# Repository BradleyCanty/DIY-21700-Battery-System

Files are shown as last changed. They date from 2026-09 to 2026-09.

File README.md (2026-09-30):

# DIY-21700-Battery-System
## Introduction
This is a do-it-yourself battery system intended for use with Unmanned Aerial Vehicles or Unmanned Ground Vehicles.

It consists of...

1) a battery using lithium ion 21700-form-factor cells, with battery configurations spanning from 6s3p to 12s6p
2) a vehicle adapter with place-to-lock/press-to-unlock latching mechanism
3) an off-vehicle charging station

(12s4p battery system configuration shown below)

<p align="center">
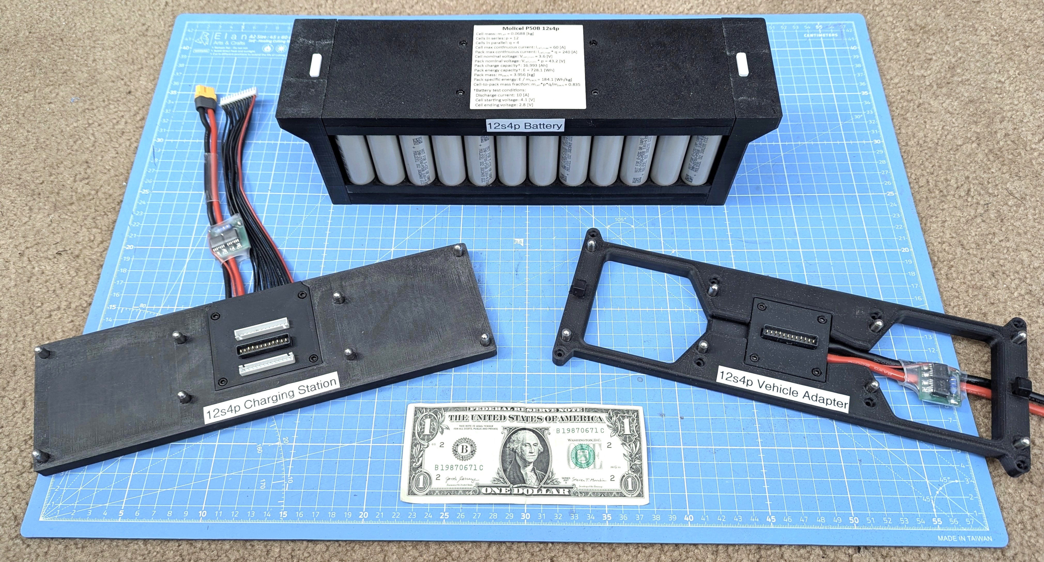
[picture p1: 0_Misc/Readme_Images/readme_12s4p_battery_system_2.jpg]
  
</p>

**This is a complete and working system, with all design files (CAD and PCB design) provided for your use:**\
Multiple battery system configurations have been built and flight tested. Additionally, all CAD models have been 3D printed to ensure they work as intended. Finally, if none of the configurations presented here suit your needs then you can create your own battery configuration, since all CAD files (Solidworks part files and STLs) and PCB design files (KiCad project files) are included here for your use.

**Version 2 will have cell voltage and temperature monitoring safety features (sent as a BATTERY_STATUS message over MAVLink to MAVLink-compatible autopilot software, such as ArduPilot and PX4) so star this repo for updates**

## Purpose
The parametric nature of this system allows designing and building a battery system specific to your vehicle's requirements. As such, **the value add of this system is threefold:**
1) you can use cells of your choice (i.e., can optimize for either power output or energy capacity) in a configuration suitable for your vehicle's operating envelope
2) you can enjoy a significant cost savings (~50% discount at the time of this writing) by building it yourself (see 'Bill of Materials' section for cost info)
3) the battery's latching mechanism presents a common interface for battery swapping (either manually or by robot arm); this is important since battery swapping vastly increases system uptime when compared with on-board charging

## Battery Mounting Choice
This battery system is designed such that the battery itself is top-mounted onto the vehicle its powering (and top-mounted onto its charging station). This mounting method was chosen to simplify battery swapping (either by human hand or by robot gripper); the process to swap the battery is as follows:
1. get within close proximity of the battery
2. translate grippers directly over the battery
3. rotate grippers to be aligned with the battery end plates
4. translate grippers underneath each end plate ledge
5. close grippers such that the end plate buttons are pressed down, thus unlatching the battery from the vehicle adapter
6. lift battery away from the vehicle
7. carry battery to its charging station

A similar but reversed process occurs for taking a fully charged battery off its charging station to the vehicle.

If you intend for such a battery to power your multirotor you might ask: "wouldn't the multirotor be top heavy, thereby adversely affecting stability and control?". The simple answer is no, it wouldn't **if you mount the battery directly above the bulkhead where the motor arms are mounted to the body**. In doing this, the center of gravity moves closer to the thrust plane (i.e. the plane where the rotors spin), which decreases overall inertia and thereby increases control responsiveness. So the overall impact is positive, not adverse. As final proof of functionality, I have personally flight tested a multirotor using a 12s4p battery, with no stability or control issues whatsoever.

(12s4p battery and vehicle adapter used on large quadcopter shown below)

<p align="center">
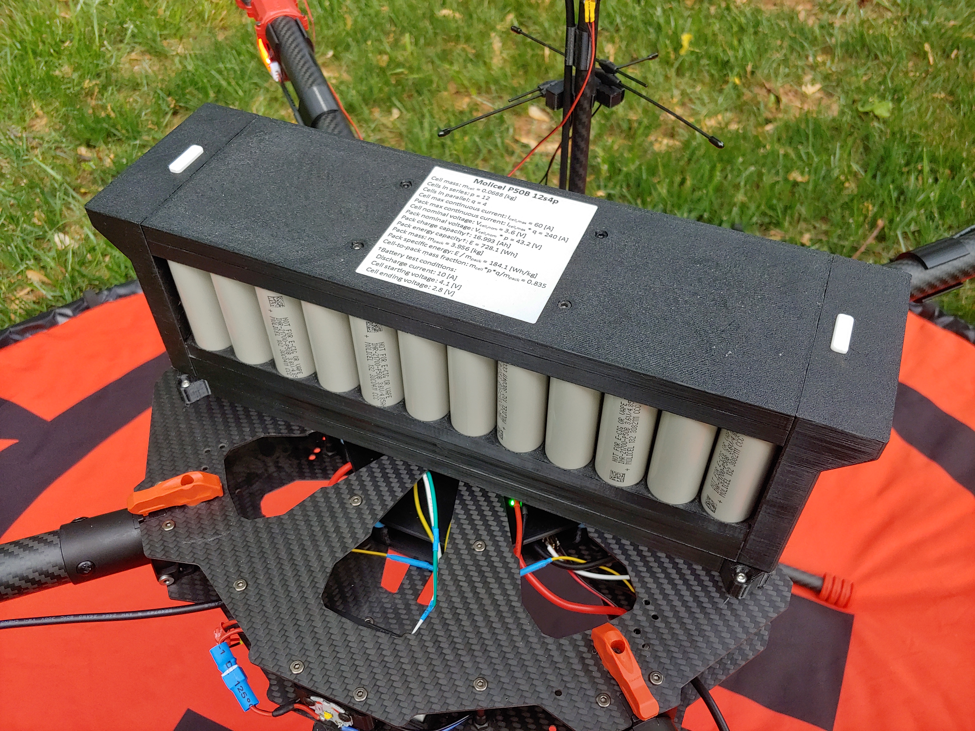
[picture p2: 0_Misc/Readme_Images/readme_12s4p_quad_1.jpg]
  
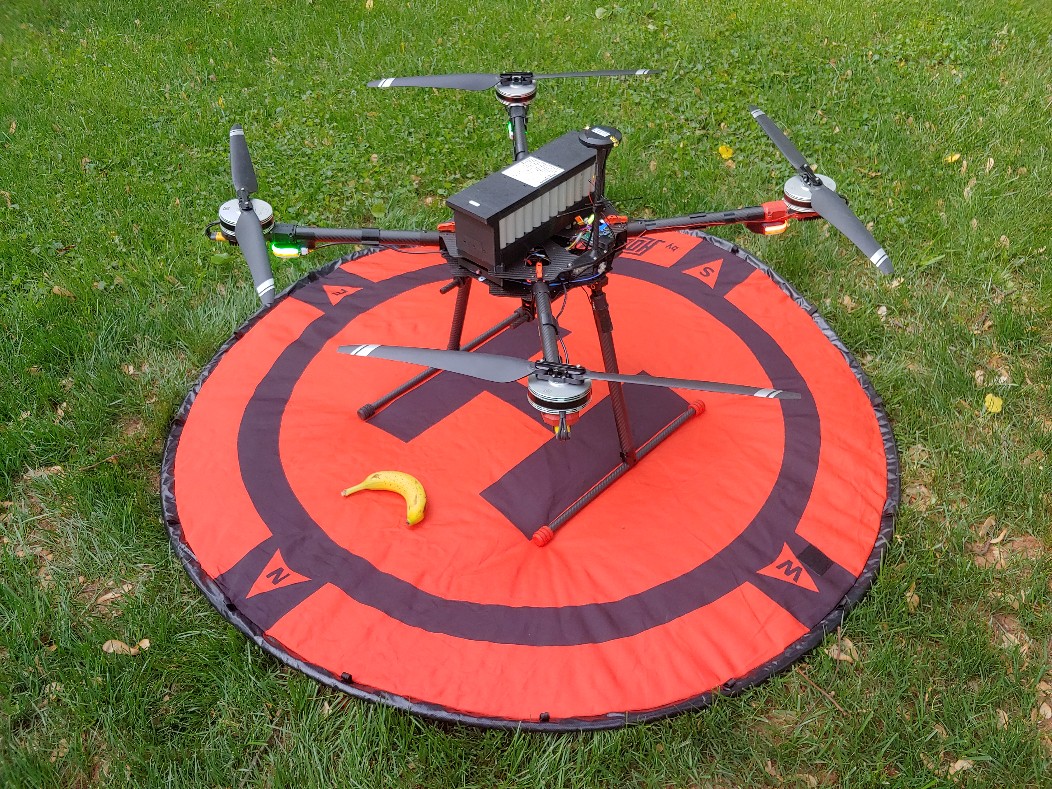
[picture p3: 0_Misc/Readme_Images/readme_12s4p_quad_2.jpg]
  
</p>

Details on mounting the vehicle adapter to the vehicle can be found in Build Step 7: [Integrate vehicle adapter into vehicle](5_Integration_and_Test_Instructions/1_Vehicle_Adapter_Integration_Instructions/vehicle_adapter_integration_instructions.md)

## Cell Form Factor Choice
Considering the cell form factor, **21700 cells** (i.e. cylindrical cells having 21[mm] height and 70[mm] length) **are used in the battery since they are cheap, easily obtained, and have high gravimetric energy density**. In comparison to other cells types, 18650 cells tend to have lower gravimetric energy density, while 4680 cells, prismatic cells, and pouch cells aren't widely available to the general public (as of late 2026). Concerning battery design, the battery configuration is defined by its number of cells in series (which sets its voltage) and its number of cells in parallel (which sets its charge capacity and its max current draw limit). In the system presented here, the possible number of cells in series ranges from 6 to 12, while the possible number of cells in parallel ranges from 3 to 6. That is, the smallest possible battery configuration is one having 6 cells in series and 3 cells in parallel (18 cells total), while the largest battery configuration is one having 12 cells in series and 6 cells in parallel (72 cells total).

(6s3p and 12s6p battery system configurations shown below)

<p align="center">
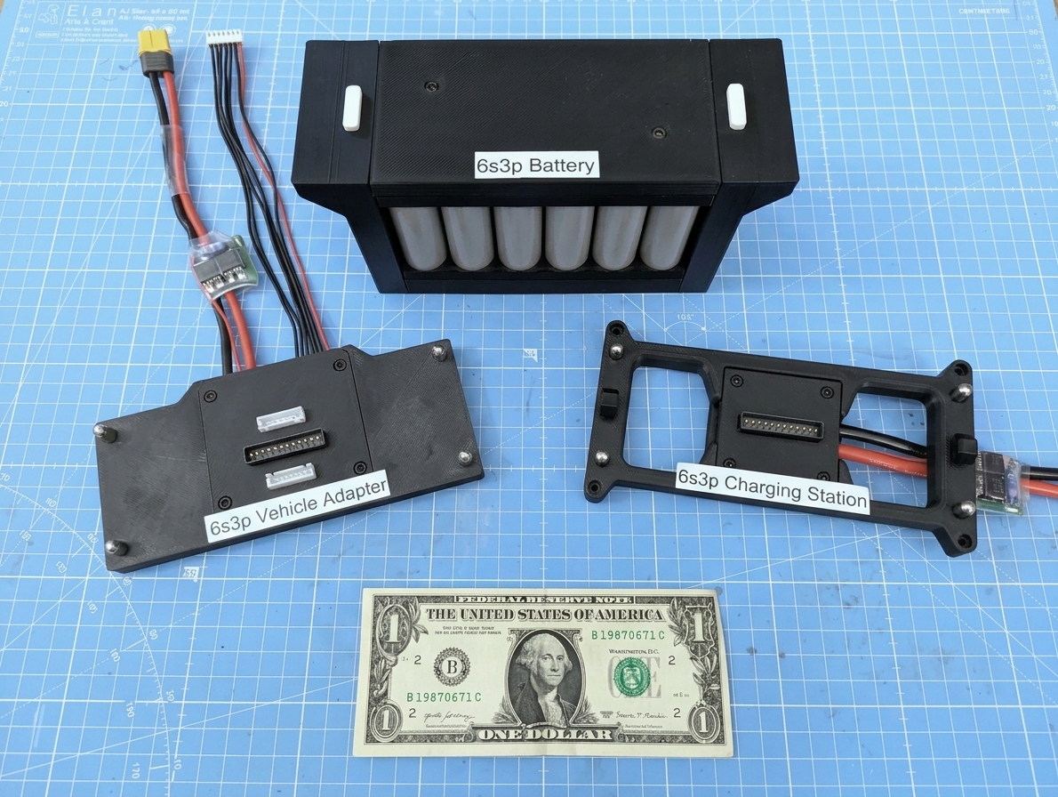
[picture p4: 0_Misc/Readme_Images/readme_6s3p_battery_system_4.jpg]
  
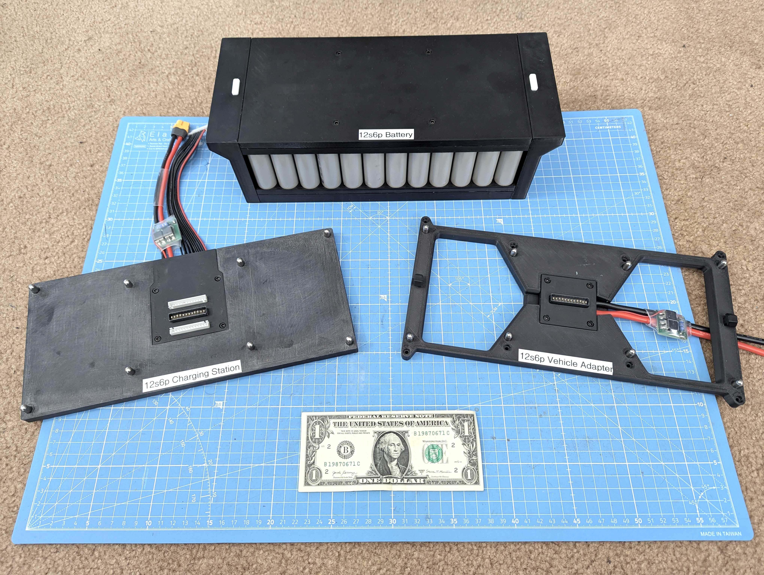
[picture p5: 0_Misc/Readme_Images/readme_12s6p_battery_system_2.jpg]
  
</p>

As a final note, **the cell-to-pack mass fraction across all battery configurations is found to be around 83%**. This value is important since once you select a specific 21700 cell to use, you can then estimate the battery's total mass and the battery's gravimetric energy density:\
$m_{battery} \approx m_{cell} * M * N / CPMF$ = battery mass [kg]\
where\
$m_{cell}$ = cell mass [kg]\
$M$ = number of cells in series\
$N$ = number of cells in parallel\
$CPMF$ = cell-to-pack mass fraction

$E_{battery}^* = (battery\ nominal\ voltage) * (battery\ charge\ capacity)$\
&nbsp; &nbsp; &nbsp; &nbsp; &nbsp; &nbsp; &thinsp;= $(M * V_{cell, nominal})*(N * Q_{cell,expected}) / m_{battery}$\
&nbsp; &nbsp; &nbsp; &nbsp; &nbsp; &nbsp; &thinsp;= gravimetric energy density [Wh/kg]\
where\
$V_{cell, nominal}$ = nominal cell voltage = 3.6[V] (for li-ion cell)\
$Q_{cell,expected}$ = expected cell charge capacity for normal vehicle operation (computed using the process outlined in 'Steps for Selecting a Battery Configuration' section found below)

For example, for a battery having 8 cells in series and 5 cells in parallel (i.e. MsNp = 8s5p) using EVE 50PL 21700 cells, we have\
$m_{cell} = 0.066 [kg]$ (real-world value... datasheet gives 0.072 [kg] per cell)\
$M$ = 8\
$N$ = 5\
$CPMF$ = 0.83\
$Q_{cell,expected}$ = 4.5 [Ah]

Then, battery mass and gravimetric energy density are computed to be\
$m_{battery} \approx 0.066 * 8 * 5 / 0.083 =  3.18$ [kg]\
$E_{battery}^* = (8 * 3.6)*(5 * 4.5) / 3.18$ = 203.8 [Wh/kg]

## Safety
Additionally, safety is paramount. A temperature sensor circuit consisting of a microcontroller and busbar voltage sensing is in progress (I had assumed thermistors would work in the cell failure detection role, but apparently the thermal mass of the busbar is too large to detect it in time). I am in the process of designing and prototyping a circuit which detects voltages at each busbar and sends them in MAVLink packets over UART to the flight controller (running either Ardupilot or PX4), with options of alerting the pilot or autolanding the vehicle if a measured busbar voltage is lower than some threshold. **The software development, physical packaging, and testing have posed significant issues which require a non-trivial amount of iteration, time, and money: I am working through these issues, but at some point I need to call a "pencils down" and declare victory, so Version 1 is without this safety feature. However, I assure you that Version 2 will have this safety feature, so stay tuned for that.** Additionally, I am in the process of making a low voltage alarm circuit featuring a buzzer and orange LED lights which buzz and flash upon low voltage detection, which I intend to include in Version 2 of this project.

Concerning the electrical system limitations, the PCBs (the 'Battery Board', 'Vehicle Adapter', and 'Antispark Board') are designed to handle 60 amps of continuous current (assuming a maximum temperature rise of 20°C). **You should consider the 60 amps of continuous current limitation as the primary limiting factor in your selected configuration.** This current limitation is written out on each PCB via silkscreen text. Note that this is max continuous current, <ins>not max short-duration current</ins>: max short-duration current is dictated by the 21700 cell you choose (should be listed in its datasheet) and the number of cells used in parallel. Specifically, its given by:

$I_{max\ total,short\ duration}$ = $I_{max\ cell} * N$\
where\
$N$ = number of cells in parallel

## DIY or Build from a Kit
Building this system consists of many steps (see 'Build Steps' section), and requires specific tools (see 'Required Tools' section). As a consequence, many people may find that doing this on their own is too advanced for them. Therefore, a kit is available to make the the build process easier: in essence, all you need to do upon receiving the kit is
1) Insert your favorite cells (purchased separately) into the fully-prepared 3D printed frames
2) spot weld the busbars to the cell terminals
3) Solder the balance cable wires to the busbars
4) Cut and solder the 8 AWG power wires to the battery PCB
5) fasten the fully-prepared 3D printed parts and pre-populated PCBs together with screws
6) Test the battery by performing a few charge/discharge cycles on your battery charger (the battery charger is not included in the kit)

Then, the tools required for building the battery system from the kit is
1) a suitable spot welder
2) soldering iron
3) metric hex wrenches
4) a suitable battery charger

Kit contents, pricing, and ordering information can be found [here](0_Misc/build_kit_info.md).

Whether you are building from raw materials or building from the kit, the 'Build Steps' section found below contains pictures and descriptions at each step to aid in the build process.

## Battery System Components in Detail
The battery system consists of the following components:
1) the battery
2) the vehicle adapter
3) the charging station

Each is explained in turn

### The Battery
Each component is sized according to the chosen battery configuration. Possible battery configurations range from 6 to 12 cells in series, and 3 to 6 cells in parallel. Spelled out, these configurations are:
* Six in series:
    - Three in parallel (6s3p)
    - Four in parallel (6s4p)
    - Five in parallel (6s5p)
    - Six in parallel (6s6p)
* Eight in series:
    - Three in parallel (8s3p)
    - Four in parallel (8s4p)
    - Five in parallel (8s5p)
    - Six in parallel (8s6p)
* Ten in series:
    - Three in parallel (10s3p)
    - Four in parallel (10s4p)
    - Five in parallel (10s5p)
    - Six in parallel (10s6p)
* Twelve in series:
    - Three in parallel (12s3p)
    - Four in parallel (12s4p)
    - Five in parallel (12s5p)
    - Six in parallel (12s6p)
  
  The battery consists of
  - two frames, which hold the cells between them
    <p align="center">
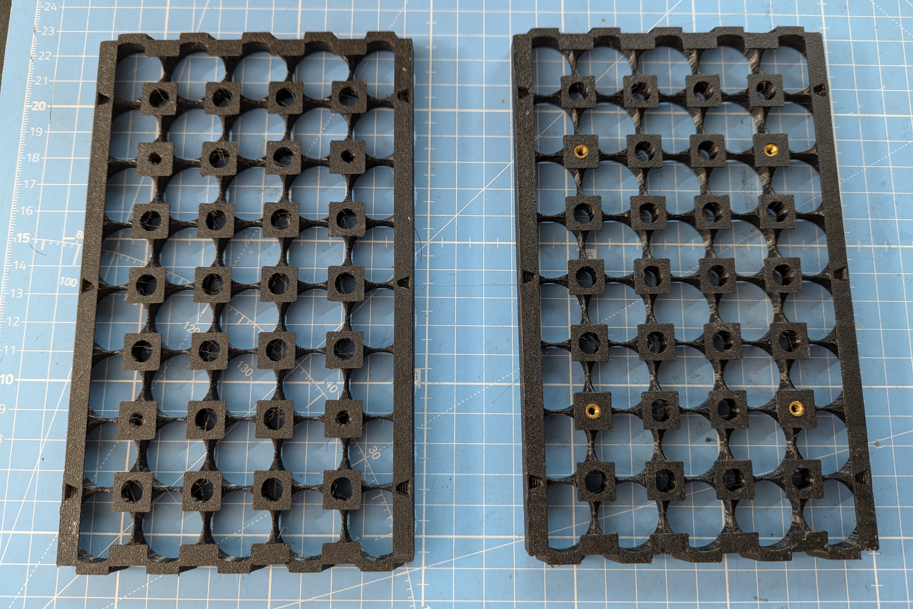
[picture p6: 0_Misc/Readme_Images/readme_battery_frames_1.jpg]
      
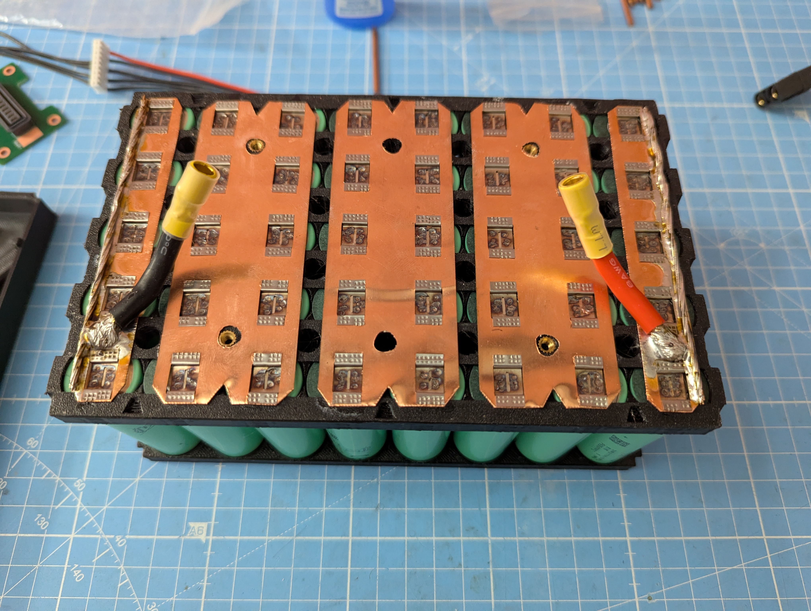
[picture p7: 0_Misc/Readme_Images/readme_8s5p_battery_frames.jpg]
      
    </p>
    
  - a top plate, which covers the top frame
    <p align="center">
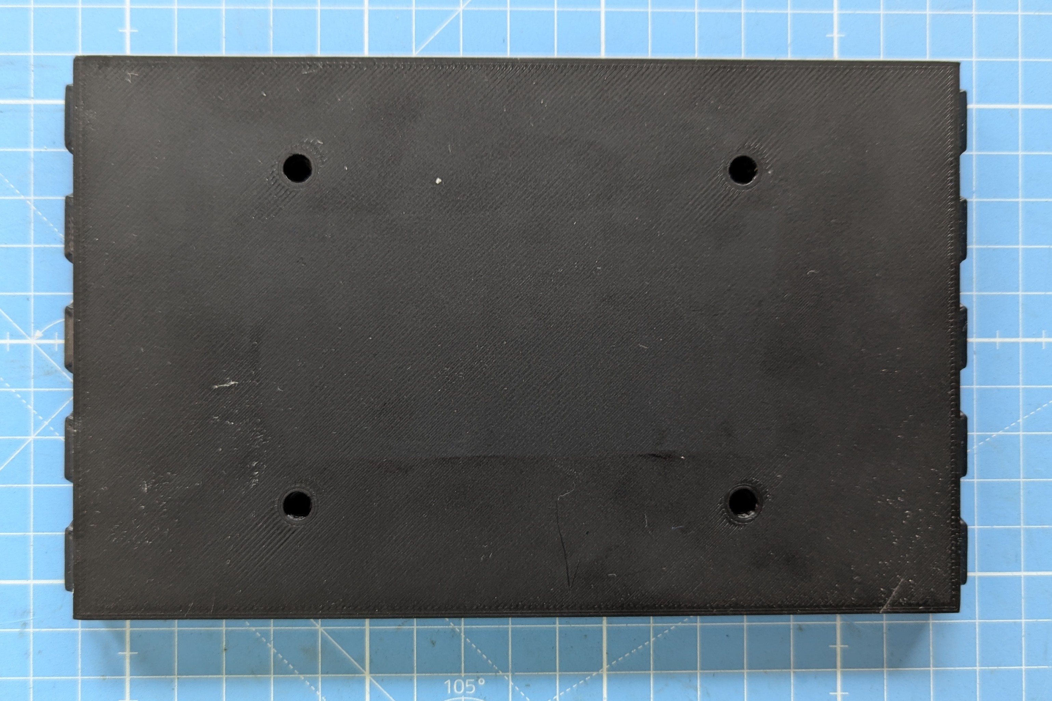
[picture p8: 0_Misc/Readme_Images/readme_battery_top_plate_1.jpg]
      
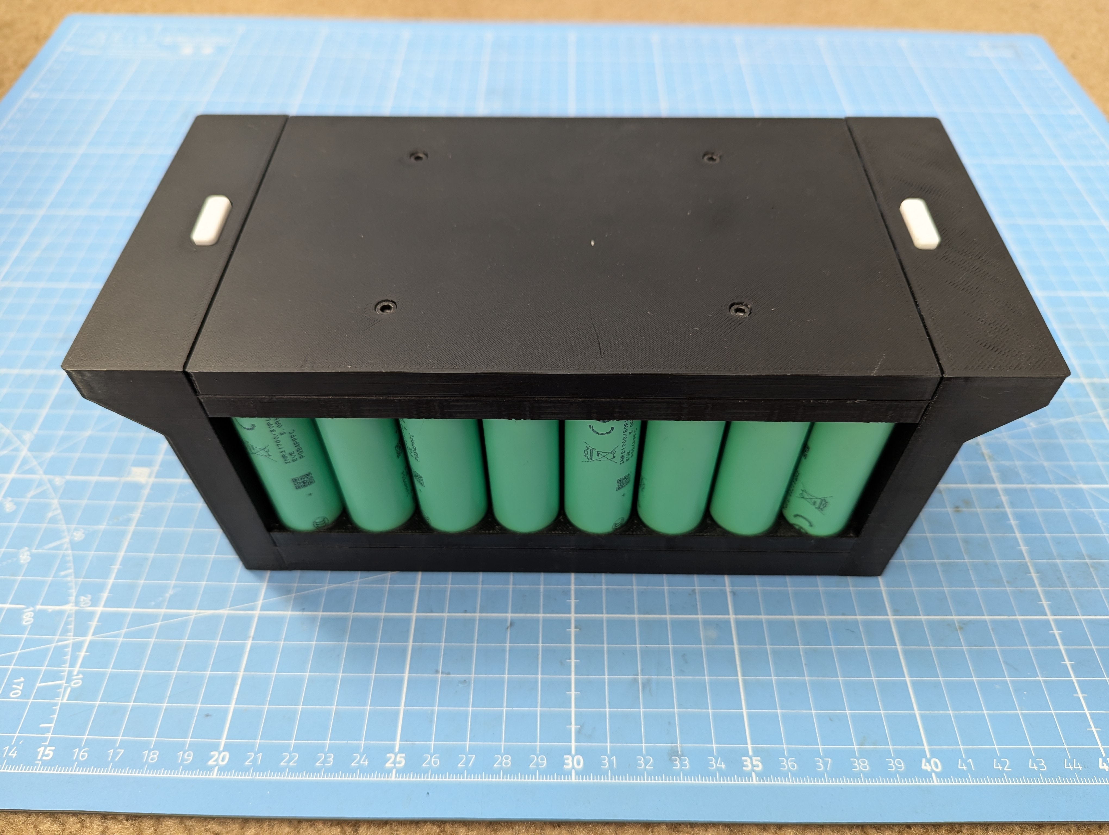
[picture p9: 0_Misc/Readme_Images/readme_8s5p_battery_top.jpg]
      
    </p>

  - a bottom plate, which connects with the bottom frame and houses the female 12-pin power and balance connectors
    <p align="center">
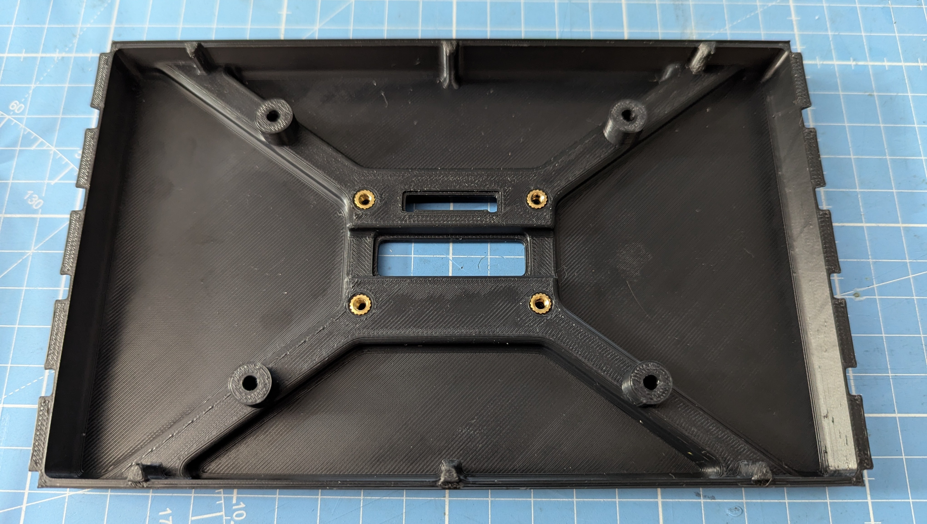
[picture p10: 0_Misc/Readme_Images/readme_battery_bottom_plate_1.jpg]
      
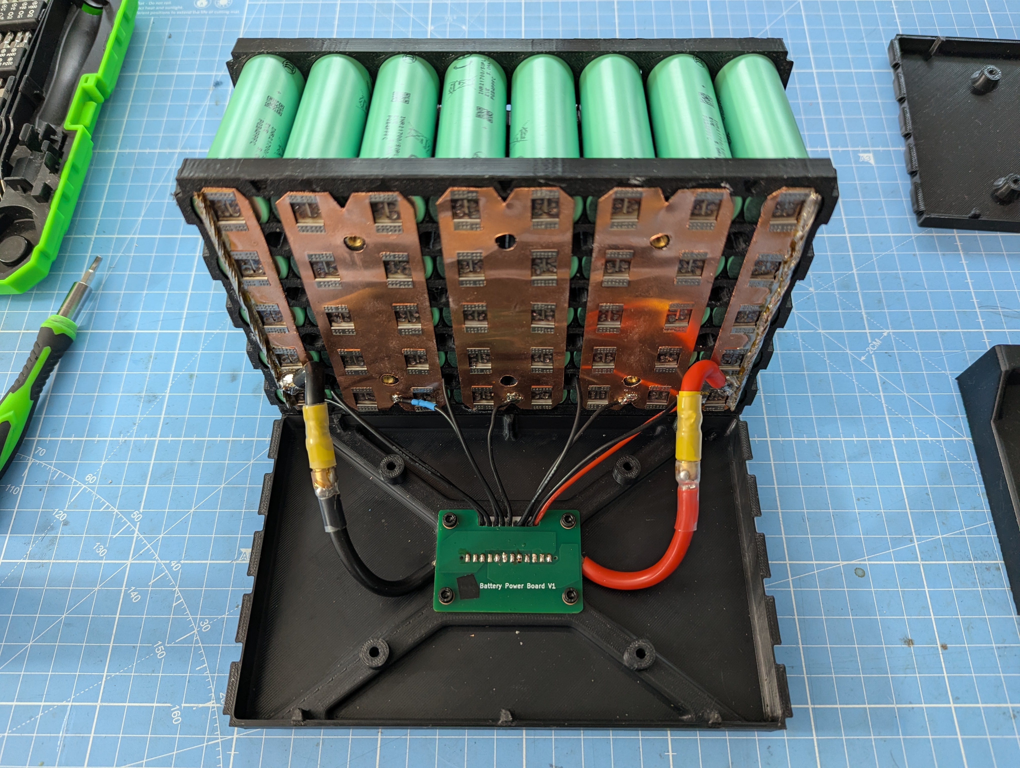
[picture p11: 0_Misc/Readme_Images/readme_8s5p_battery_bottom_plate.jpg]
      
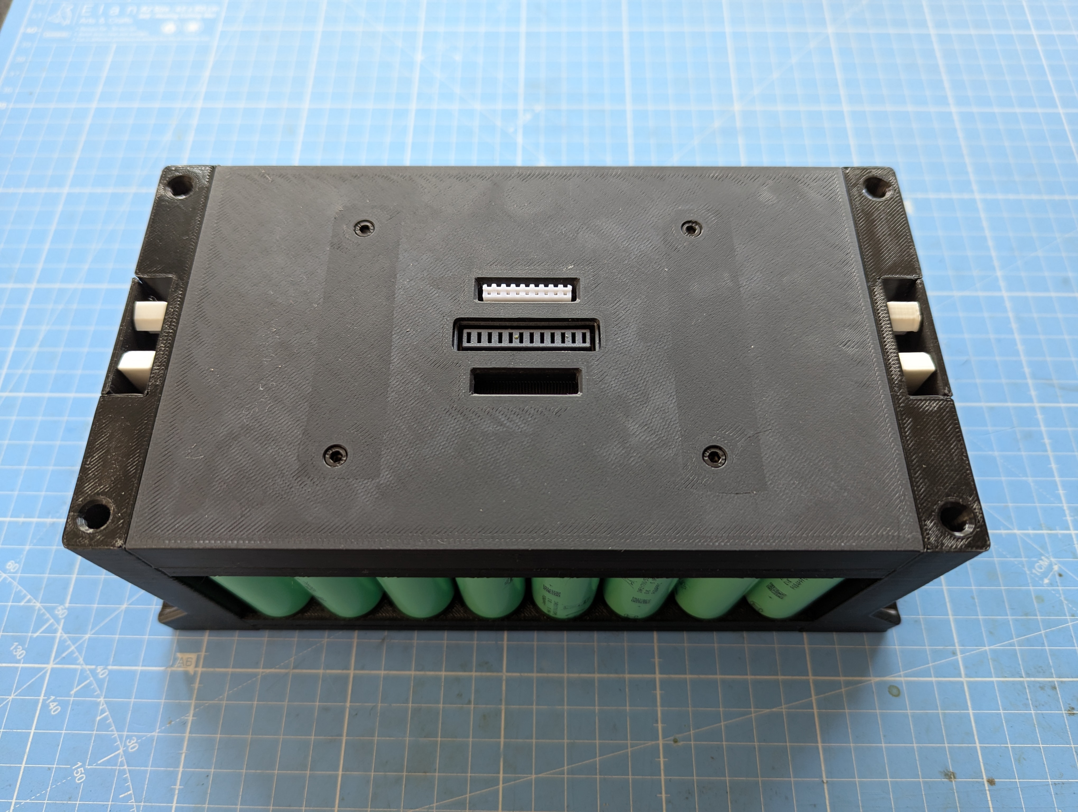
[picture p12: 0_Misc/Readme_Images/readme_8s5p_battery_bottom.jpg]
      
    </p>
    
  - two end plates, which clamp the frames together and serve as handles containing the button-press-to-unlatch mechanism
    <p align="center">
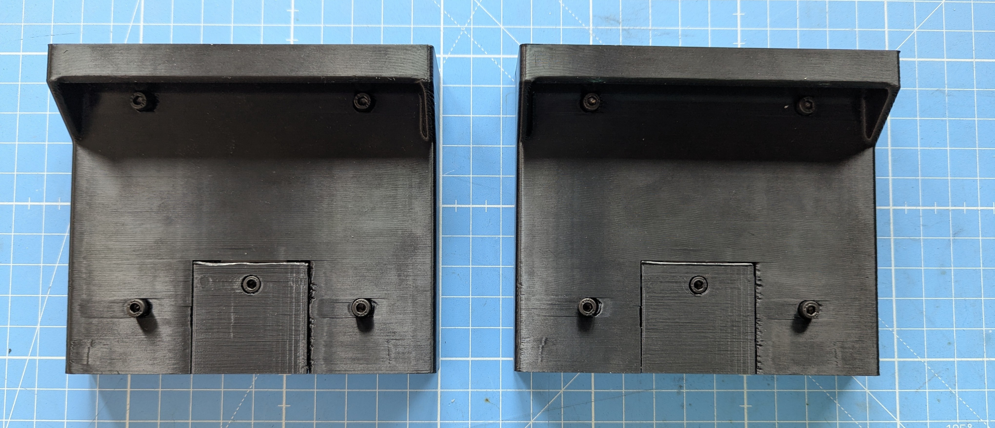
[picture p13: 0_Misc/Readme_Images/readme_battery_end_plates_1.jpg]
      
    </p>
  
### The Vehicle Adapter
Connects the battery with the vehicle, both mechanically and electrically. For the mechanical interface, it has two latches which interface with the two button-press-to-unlatch mechanisms on either end of the battery. For the electrical interface, it has a male 12-pin connector.
  <p align="center">
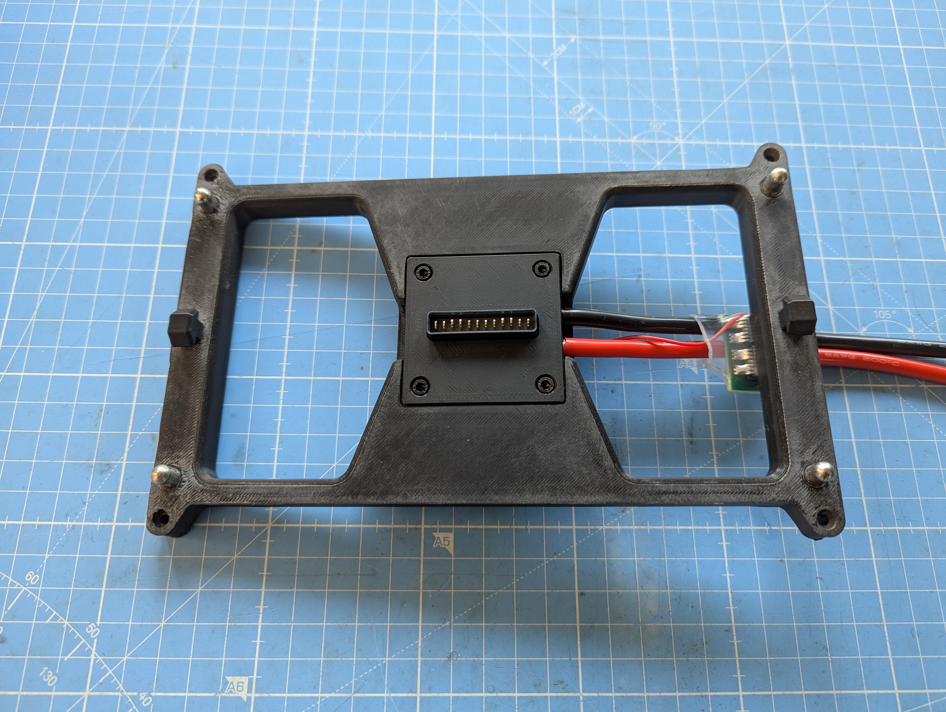
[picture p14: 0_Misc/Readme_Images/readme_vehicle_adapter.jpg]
    
  </p>

### The Charging Station
Interfaces the battery with a standard RC battery charger via XT60 connector for power and JST-XH connector for balancing. Again, <ins>this is not a charger itself: its an interface between the battery and the charger</ins>.
<p align="center">
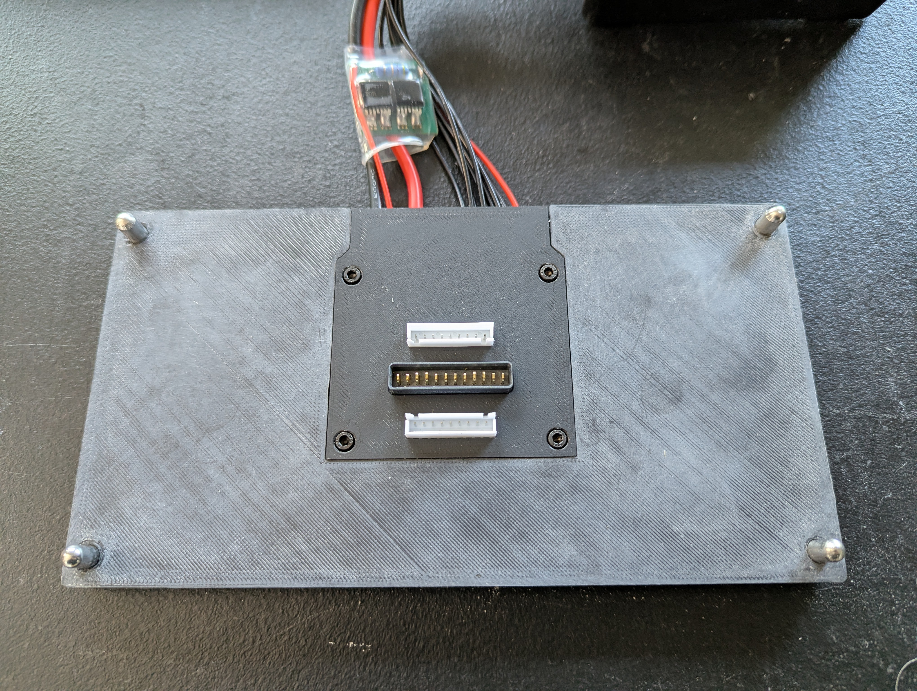
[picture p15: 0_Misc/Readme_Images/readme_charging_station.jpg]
  
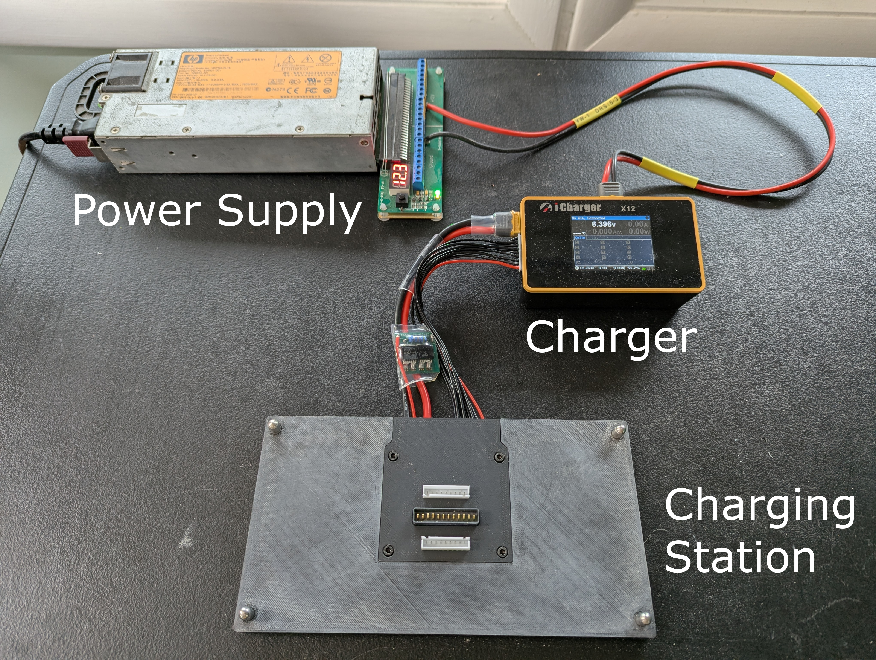
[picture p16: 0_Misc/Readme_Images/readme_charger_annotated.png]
  
</p>

## Steps for Selecting a Battery Configuration
In general,\
**The number of cells in series determines the battery voltage:**\
$battery\ max\ voltage = (cell\ max\ voltage) * (number\ of\ cells\ in\ series)$\
where\
$cell\ max\ voltage$ = 4.1 V (for LiIon cells)

**The number of cells in parallel determines the battery charge capacity:**\
$$battery\ charge\ capacity = (cell\ expected\ charge\ capacity) * (number\ of\ cells\ in\ parallel)$$\
where\
$cell\ expected\ charge\ capacity$ = a function of expected average current draw in cruise (fixed wing) or hover (VTOL)

Specifically, to find the battery's expected charge capacity, check the 21700 cell's datasheet for the plot of Voltage vs Charge Capacity (which contains curves of various discharge rates) and then match your vehicle's expected average current draw divided by the number of cells in parallel to the corresponding discharge rate curve in the plot. Finally, find the cell's capacity corresponding to an "empty" voltage of around 2.8 V, and then multiply it by the number of cells in parallel to get the battery's charge capacity.

For example, suppose you are using Molicel P50B cells in an 8s5p battery configuration on a vehicle expected to draw 1300 Watts of power in nominal operation, then the steps to find the expected charge capacity are as follows: 

1) Compute the average discharge current in nominal operation:\
   $I_{avg}$ = $P_{nominal}$ / $V_{batt,nominal}$ = $P_{nominal}$ / ($V_{cell,nominal}$ * M)\
   where\
   M = number of cells in series = 8\
   $V_{cell,nominal}$ = li-ion cell nominal voltage = 3.6V
   
   Plugging in the values...\
   $I_{avg}$ = 1300 / (3.6 * 8) = 45.1 Amps
   
2) Compute the discharge rate per cell: 45.1 Amps / 5 cells in parallel = 9.03 Amps
3) Find the Voltage vs Charge capacity plot in the Molicel P50B datasheet
4) On the plot, draw a horizontal line at the cutoff voltage (here 2.8V) across the plot, and stop upon reaching the curve corresponding to the cell's discharge rate (here the 10 Amp curve)
5) On the plot, draw a vertical line to the abscissa to obtain the cell's nominal charge capacity
(see plot below)

<p align="center">
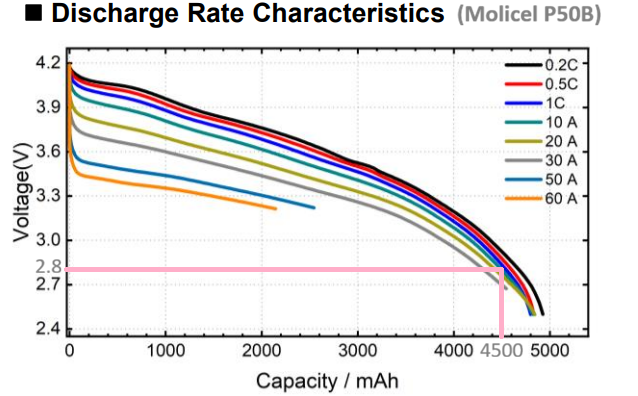
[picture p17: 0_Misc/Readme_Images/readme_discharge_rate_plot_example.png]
  
</p>

6) Finally, compute the battery's nominal charge capacity:\
   $Q_{batt,nominal}$ = $Q_{cell,nominal}$ * M\
   where\
   M = number of cells in parallel = 5

   Plugging in the values...\
   $Q_{batt,nominal}$ = 4500 * 5 = 22500 mAh = 22.5 Ah

Once battery nominal charge capacity is found, you can **compute the vehicle's expected endurance** (i.e. operating time under nominal conditions) using the following equation:\
t = $V_{batt,nominal}$ * $Q_{batt,nominal}$ / P\
where\
$V_{batt,nominal}$ = $V_{cell,nominal}$ * M

Using the values from the previous example, we have...\
t = (3.6 * 8) * 22.5 / 1300 = 0.498 hours = 29.9 minutes

This is all predicated on the accuracy of your predicted power draw, which is a function of your payload mass, battery mass, structure mass, and the type of motors (and, for multirotors, the size of the rotors) used on the vehicle. **So, in summary, selecting a battery configuration is an iterative process.**

For a multirotor, the appropriate battery configuration can be determined using this [multirotor design methodology](0_Misc/multirotor_design_methodology.md).

## Required Tools
* Soldering iron (for general soldering)
* Threaded insert soldering iron tip 
* Hot plate (for SMD soldering)
* Spot welder (for battery bus bar welding)
* 3D printer
* Deburr tool (for removing edge artifacts from 3D prints)
* Wire stripper
* Wire cutter
* Super glue
* Sheet metal shears (for cutting busbars)
* Hand drill or drill press (for cutting wire pass-through holes into busbars)

## Bill of Materials (BOM)
The battery BOM is found [here](3_Bill_of_Materials/battery_bom.md)

The vehicle adapter BOM is found [here](3_Bill_of_Materials/vehicle_adapter_bom.md)

The charging station BOM is found [here](3_Bill_of_Materials/charging_station_bom.md)

## Build Steps
### Things you should know before starting:
* ASA filament is used in all the 3D printed parts since it's ultraviolet resistant, so it can be left outdoors without degrading in strength. However, 3D printing it releases toxic fumes (specifically, printing it releases volatile organic compounds along with ultrafine particles, either of which may be carcinogenic), so use a fan-filter system when printing ASA. Also, ASA is prone to warping and so must be printed in a heated enclosure. Even with a heated enclosure, a brim is often needed on large parts to keep them from peeling away from the print bed. If the peeling at edges occurs at any time during the print, its a failed print so cancel it and reprint it with a 5 mm increase to the brim width. Do this iteratively until the print is successful.
* The printed circuit boards (PCBs) can be manufactured by uploading the zipped gerber files (provided in the repo) to a PCB manufacturer, such as PCBWay or JLCPCB
* The PCB components can be purchased from electronic component suppliers, such as DigiKey or Mouser, but know that you will need to hand-solder the through-hole components and hot plate solder the SMD components
* The build process is very frustrating and time-consuming, especially
    - 3D printing the parts, with ASA prints likely to fail due to warping
    - populating the antispark circuits with SMD components and soldering them using a hot plate
    - cutting wires to length and soldering them
    
    To save time and frustration, pre-made kits for each battery configuration are available for purchase: see 'DIY or Build from a Kit' section above for details on ordering a kit.

### To make the build process as simple as possible, proceed in this order:
  1. **Decide on a battery configuration**
  2. **Order the required PCBs and associated components:**\
     each system needs two antispark PCBs, one charging station PCB (pick the one that matches your configuration), one battery PCB (pick the one that matches your configuration), and one vehicle adapter PCB, all found [here](2_PCB_Files). See the READMEs for BOMs and ordering information.
     
  4. **Build the antispark boards:** instructions found [here](4_Build_Instructions/1_Antispark_Build_Instructions/antispark_build_instructions.md)
  5. **Build the charging station:** instructions found [here](4_Build_Instructions/2_Charging_Station_Build_Instructions/charging_station_build_instructions.md)
  7. **Build the battery:** instructions found [here](4_Build_Instructions/3_Battery_Build_Instructions/battery_build_instructions.md)
  8. **Build the vehicle adapter:** instructions found [here](4_Build_Instructions/4_Vehicle_Adapter_Build_Instructions/vehicle_adapter_build_instructions.md)
  9. **Integrate vehicle adapter into vehicle:** instructions found [here](5_Integration_and_Test_Instructions/1_Vehicle_Adapter_Integration_Instructions/vehicle_adapter_integration_instructions.md)
  10. **Perform vehicle operating envelope testing:** instructions found [here](5_Integration_and_Test_Instructions/2_Vehicle_Envelope_Testing_Instructions/vehicle_envelope_testing_instructions.md)

## TO DO
### V1 TO DO IMMEDIATELY
* Consolidate and simplify the battery sizing methodology

### V1 TO DO LATER
* Take pictures of antispark circuit build and put into instructions
* Complete the 'Perform vehicle operating envelope testing' instructions

### V2 TO DO IMMEDIATELY
* Replace JST-XH balance connectors used in battery interface with machine header pins: female on battery, male on vehicle adapter and charging station
* Implement safety features: measure voltages at each busbar, and measure temperatures at two cells, and report as a BATTERY_STATUS message over MAVLink
* Refactor end plate latching mechanism to have clamp-from-top-to-unlatch, replacing the button-press-to-unlatch. This makes the battery usable on fixed-wing platforms, since battery swapping operations interact with the top surface only, as opposed to V1 where side clasping is required. It will also probably make it easier to automate battery swapping via robot arm, due to the simplified interface.

### V2 TO DO LATER
* Replace balance wires with a BMS
* Extend battery configurations to 24s12p

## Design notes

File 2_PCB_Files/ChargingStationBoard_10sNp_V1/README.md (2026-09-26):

## KiCad 3D View
Below are the screenshots of this board from KiCad's 3D board viewer.
<p align="center">
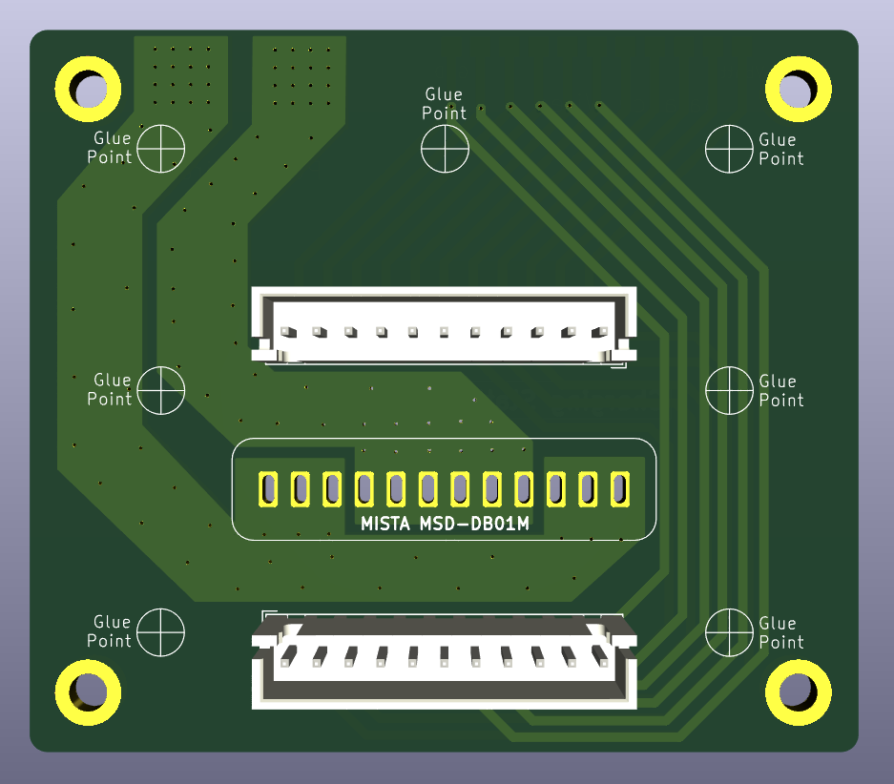
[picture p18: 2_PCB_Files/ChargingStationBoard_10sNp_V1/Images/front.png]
  
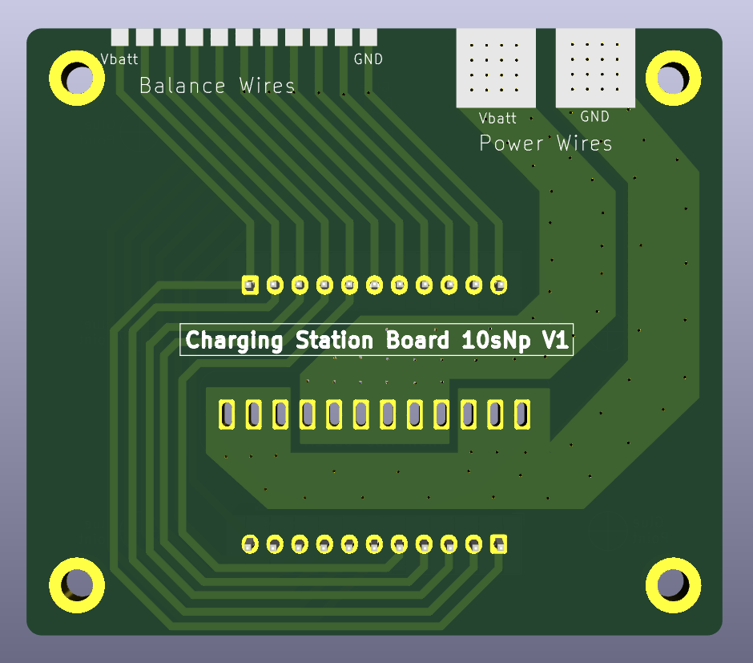
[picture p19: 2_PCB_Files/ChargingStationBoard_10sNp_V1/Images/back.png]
  
</p>

## How to Purchase the Board
To purchase PCBs, take the zipped 'fab' directory (which contains PCB manufacturing instructions) and upload it to a PCB manufacturer's website (e.g. [JLCPCB](https://JLCPCB.com) or [PCBWay](https://PCBWay.com))

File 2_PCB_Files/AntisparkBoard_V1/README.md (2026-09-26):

## KiCad 3D View
Below are the screenshots of this board from KiCad's 3D board viewer.
<p align="center">
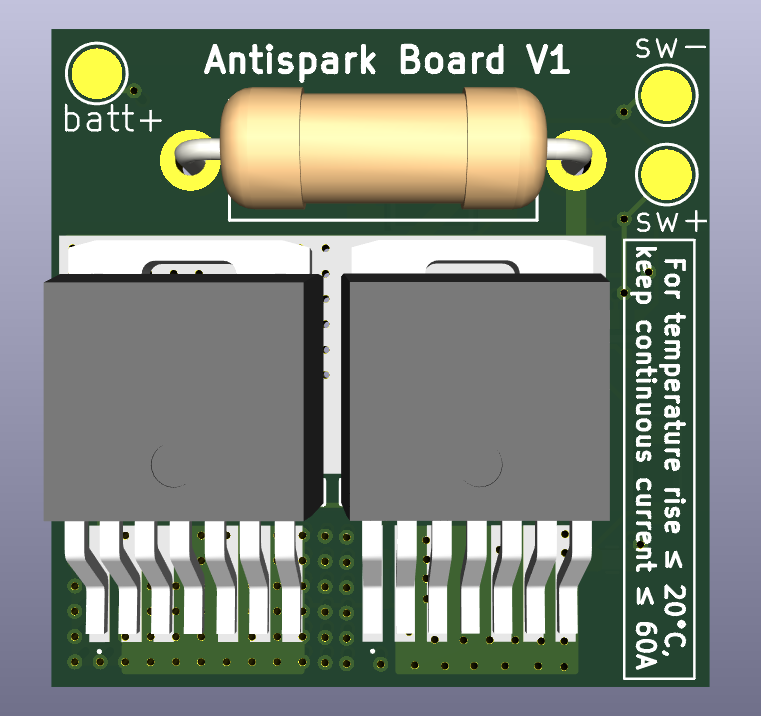
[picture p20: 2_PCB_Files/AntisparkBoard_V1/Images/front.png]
  
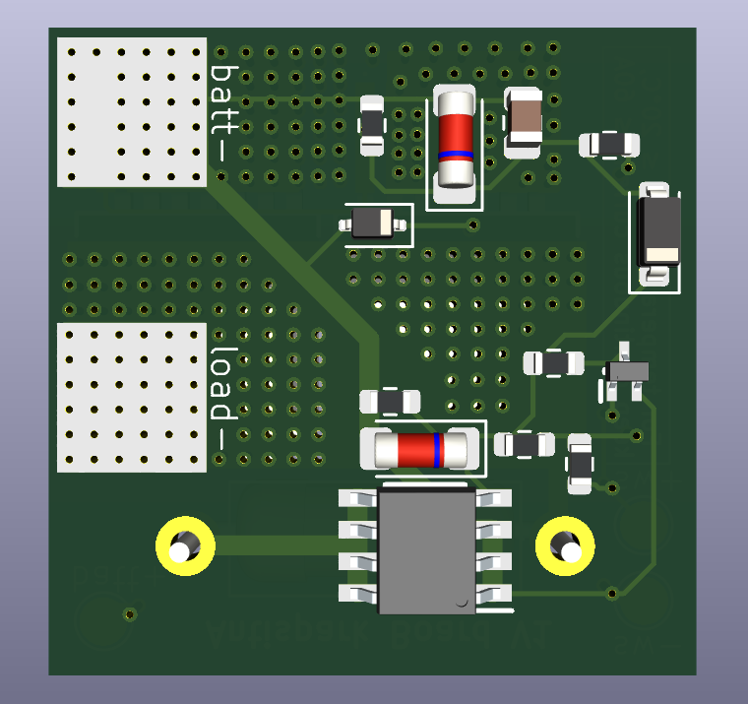
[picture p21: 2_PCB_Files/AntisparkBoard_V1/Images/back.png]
  
</p>

## BOM
| References | Value | Footprint | Quantity |
| --- | --- | --- | --- |
| C1 | 4.7 μF | C_0805_2012Metric | 1 |
| R1, R2, R4, R5 | 1 MΩ | R_0603_1608Metric | 4 |
| R3 | 4.7 Ω | R_Axial_DIN0414_L11.9mm_D4.5mm_P15.24mm_Horizontal | 1 |
| R6 | 100 kΩ | R_0603_1608Metric | 1 |
| R7 | 100 Ω | R_0603_1608Metric | 1 |
| D1, D2 | 12 V | D_MiniMELF | 2 |
| D3 | Zener 0.5 V | D_SOD-123 | 1 |
| D4 | 10 V | D_SOD-323 | 1 |
| Q1, Q2 | IRFS7530TRL7PP | IRFS7530TRL7PP | 2 |
| Q3 | FDS5670 | SOIC127P600X175-8N | 1 |
| Q4 | NTA4001NT1G | SOT50P160X90-3N | 1 |

## How to Purchase the Board and Components
To purchase PCBs, take the zipped 'fab' directory (which contains PCB manufacturing instructions) and upload it to a PCB manufacturer's website (e.g. [JLCPCB](https://JLCPCB.com) or [PCBWay](https://PCBWay.com))

To purchase components, I recommend [Digikey](https://digikey.com) or [Mouser](https://mouser.com)

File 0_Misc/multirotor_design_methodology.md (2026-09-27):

# Multirotor Design Methodology

Designing a multirotor around specific **payload weight ($W_p$)** and **endurance ($t$)** constraints is an iterative sizing process. You must balance energy density, motor-propeller efficiency, and structural mass.

---

## 1. Initial Mass Estimation

To size components, estimate your **Maximum Takeoff Weight (MTOW)** ($W_{mtow}$). A common rule of thumb for endurance multirotors is that payload accounts for **15% to 25%** of the total aircraft mass ($m_{tot}$).

$$\text{MTOW} \approx \frac{W_p}{0.20}$$

* **Structural Mass ($m_{frame}$):** ≈ 20% – 25% of MTOW
* **Battery Mass ($m_{bat}$):** ≈ 45% – 55% of MTOW
* **Payload Mass ($m_{payload}$):** ≈ 20% of MTOW
* **Avionics & Motors ($m_{elec}$):** ≈ 10% – 15% of MTOW

---

## 2. Power and Propulsion Sizing

### A. Thrust-to-Weight Ratio
For a stable multirotor, aim for a thrust-to-weight ratio between **1.8:1 and 2.2:1** at maximum throttle.

$$\text{Total Required Thrust} \approx 2.0 \times \text{MTOW}$$

$$\text{Thrust Per Motor} = \frac{\text{Total Required Thrust}}{\text{Number of Motors ($N$)}}$$

### B. Propeller Selection
Endurance scales directly with propeller disc area and pitch-to-diameter ratio:
* **Large Diameter + Low Pitch:** Higher aerodynamic efficiency ($\text{g/W}$) at hover. Select the largest propeller size your frame footprint allows.
* Look for carbon fiber props designed for low-RPM endurance (e.g., T-Motor P-series).

### C. Motor KV Selection
Match the motor KV to the propeller size and battery voltage ($V$):
* **High Payload / High Endurance:** Low KV motors (100–400 KV) paired with high voltage (6S to 12S LiPo/Liion).
* **Hover Efficiency Target:** Target a motor/propeller combination that achieves **$\ge 8 \text{ to } 10 \text{ g/W}$** at hover thrust ($W_{mtow} / N$).

---

## 3. Battery Configuration & Energy Budget

To achieve high endurance ($>30\text{ minutes}$), battery chemistry choice is critical:

* **LiPo (Lithium Polymer):** Higher discharge C-rate, lower energy density ($\sim 180\text{–}220 \text{ Wh/kg}$). Best for heavy payloads or high-wind environments requiring quick throttle response.
* **Li-ion (Lithium-ion):** Higher energy density ($\sim 250\text{–}300 \text{ Wh/kg}$ using 18650/21700 cells), but lower C-rate capability. Ideal for long-endurance, steady hover, or light-payload profiles.

### Estimating Hover Time ($t$)

1. **Calculate Hover Power ($P_{hover}$):**
   $$P_{hover} = \frac{\text{MTOW (g)}}{\eta_{hover} \text{ (g/W)}}$$
   *(where $\eta_{hover}$ is prop/motor efficiency in g/W at hover thrust)*

2. **Calculate Required Battery Capacity ($E_{req}$ in Wh):**
   $$E_{req} = \frac{P_{hover} \times t \text{ (hours)}}{\text{DOD}}$$
   *(where DOD is Depth of Discharge, typically 0.80 for battery longevity)*

3. **Verify Battery Weight:**
   $$m_{bat} = \frac{E_{req}}{\text{Specific Energy (Wh/kg)}}$$

If calculated $m_{bat}$ significantly exceeds your initial target mass fraction ($>55\%$), you must reduce payload, increase prop size/efficiency, or lower your target endurance.

---

## 4. Design & Iteration Workflow

1. **Define Hard Requirements**
   * *Set non-negotiable mission specs:* Establish payload weight ($W_p$), target flight time ($t$), maximum dimensions/frame envelope, and operating environment (wind, altitude).
2. **Select Battery Chemistry**
   * *LiPo vs. Li-ion:* For flights under 30 minutes, choose LiPo. For low-current endurance flights over 30–45+ minutes, configure a custom Li-ion pack (e.g., 6S6P 21700 cells).
3. **Size Propellers and Motors**
   * *Maximize hover efficiency:* Consult manufacturer thrust/power tables (e.g., T-Motor, KDE Direct). Find a motor + prop combination yielding $\ge 9 \text{ g/W}$ at hover thrust for your estimated MTOW.
4. **Select Frame & Layout**
   * *Quad vs. Hexa vs. Octo:*
     * **Quad (X4):** Highest efficiency (lowest frame weight and parasitic drag).
     * **Hexa / Coaxial (X8):** Better wind tolerance and redundancy for expensive payloads.
5. **Refine Mass Budget & Validate**
   * *Iterate until convergence:* Sum actual component masses ($m_{frame} + m_{motors} + m_{esc} + m_{fc} + m_{payload} + m_{bat}$). Re-calculate $P_{hover}$ and $t$. Repeat steps until total mass and required flight time converge.

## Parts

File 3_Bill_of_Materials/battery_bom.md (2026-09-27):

# Battery Bill of Materials
| Item | Quantity | Unit Cost | Total Cost | Notes |
| :--- | :--- | :--- | :--- | :--- |
| Black ASA | 0.5 kg | $10 | $10 | |
| White ASA | 0.25 kg | $5 | $5 | |
| Torsion spring | 4 | $0.5 | $2 | 1.2 mm × 10 mm × 3 laps × 120° |
| Small dowel pin | 4 | $0.1 | $0.4 | Diameter = 3 mm <br> Length = 12 mm |
| 21700 cell | M × N | C | M × N × C | M = # of cells in series<br>N = # of cells in parallel |
| Battery PCB | 1 | $6.4 | $6.4 | |
| M3 × 4 mm × 5 mm brass threaded insert nut | 16 | $0.1 | $1.6 | |
| 8 AWG black wire | 10 cm | $1 | $1 | |
| 8 AWG red wire | 10 cm | $1 | $1 | |
| 14 AWG bare copper wire | 20 cm | $2 | $2 | |
| Female 12-pin, 2.7 mm pitch blade connector | 1 | $4 | $4 | Model: MISTA MSD-DB01F-12P |
| 6 mm male bullet connector | 2 | $0.25 | $0.5 | |
| 6 mm female bullet connector | 2 | $0.25 | $0.5 | |
| JST-XH M+1-pin connector w/ wires | 1 | $1.5 | $1.5 | M = # of cells in series |
| M3 × 3 mm × 5 mm brass threaded insert nut | 2 | $0.1 | $0.2 | |
| M3 × 16 mm bolt | 8 + Q | $0.1 | $0.8 + $0.1 × Q | if N = 3, Q = 0; else Q = 4 |
| M3 × 12 mm bolt | 4 | $0.1 | $0.4 | |
| M3 × 6 mm bolt | 4 | $0.1 | $0.4 | |
| M3 × 5 mm bolt | 4 - Q | $0.1 | $0.4 - $0.1 × Q | if N = 3, Q = 0; else Q = 4 |
| Nickel-plated copper strip | S | $25.5 | $25.5 × S | Source from AliExpress<br>cell-to-cell distance = 22.5 mm<br>2p strip: each strip has 36 terminals along its length<br>S = ⌈M × N / 36⌉<br>e.g. if config. is 8s5p then M = 8 & N = 5<br>S = ⌈8 × 5 / 36⌉ = ⌈40 / 36⌉ = ⌈1.111⌉ = 2 |
---

**Total Cost** = `$38.5 + (M × N × C) + ($25.5 × S)`\
where\
**M** = # of cells in series\
**N** = # of cells in parallel\
**C** = unit cost of chosen 21700 cell\
**S** = `⌈(M × N) / 36⌉` = number of nickel-plated copper strips

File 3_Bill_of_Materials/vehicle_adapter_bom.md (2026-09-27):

# Vehicle Adapter Bill of Materials
| Item | Quantity | Unit Cost | Total Cost | Notes |
| :--- | :--- | :--- | :--- | :--- |
| Black ASA filament | 0.5 kg | $10 | $10 | |
| Antispark PCB | 1 | $12 | $12 | Source from JLCPCB or PCBWay |
| Antispark components | (see BOM) | N/A | $18 | See antispark BOM<br>Source from DigiKey or Mouser |
| Vehicle adapter PCB | 1 | $6.4 | $6.4 | Source from JLCPCB or PCBWay |
| XT90 female connector | 1 | $1 | $1 | |
| 8 AWG Wire, red | 20 cm | $1 | $1 | |
| 8 AWG wire, black | 20 cm | $1 | $1 | |
| Clear shrink tube | 1 | $0.1 | $0.1 | Diameter = 27 mm<br>Length = 40 mm |
| M3 × 6 mm bolt | 4 | $0.1 | $0.4 | |
| 28 AWG wire, red | 10 cm | $0.1 | $0.1 | |
| male 12-pin, 2.7 mm pitch blade connector | 1 | $4 | $4 | Model: MISTA MSD-DB01M-12P <br> Source from AliExpress |
| Rounded dowel pins | Q | $0.5 | Q × $0.5 | Diameter = 6 mm <br> Length = 15 mm <br> M = # of cells in series<br>if M ≤ 8, then Q = 4<br>else, Q = 8 |
---

**Total cost** = `$54.0 + Q × 0.5`\
where\
**Q** = # of rounded dowel pins\
**M** = # of cells in series\
If `M ≤ 8` then `Q = 4`; else, `Q = 8`

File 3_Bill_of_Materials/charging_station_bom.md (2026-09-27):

# Charging Station Bill of Materials
| Item | Quantity | Unit Cost | Total Cost | Notes |
| :--- | :--- | :--- | :--- | :--- |
| Black ASA filament | 0.5 kg | $10 | $10 | |
| Antispark PCB | 1 | $12 | $12 | Source from PCBWay or JLCPCB |
| Antispark components | (See BOM) | N/A | $18 | See antispark BOM<br>Source from DigiKey or Mouser |
| Charging Station PCB | 1 | $6.4 | $6.4 | Source from PCBWay or JLCPCB |
| JST-XH female M+1-pin connector w/ wires | 1 | $1.5 | $1.5 | M = # of cells in series |
| JST-XH male M+1-pin connector | 2 | $0.25 | $0.5 | M = # of cells in series |
| male 12-pin, 2.7 mm pitch blade connector | 1 | $4 | $4 | Model: MISTA MSD-DB01M-12P <br> Source from AliExpress |
| XT60 female connector | 1 | $0.5 | $0.5 | |
| Large clear shrink tube | 1 | $0.1 | $0.1 | Diameter = 27 mm<br>Length = 40 mm |
| Small clear shrink tube | 1 | $0.1 | $0.1 | Diameter = 12 mm<br>Length = 40 mm |
| Rounded dowel pins | Q | $0.5 | Q × $0.5 | Diameter = 6 mm <br> Length = 15 mm <br> M = # of cells in series<br>if M ≤ 8, then Q = 4<br>else, Q = 8 |
| 28 AWG wire, red | 10 cm | $0.1 | $0.1 | |
| 12 AWG wire, red | 20 cm | $0.2 | $0.2 | |
| 12 AWG wire, black | 20 cm | $0.2 | $0.2 | |
| M3 × 6 mm bolts | 4 | $0.1 | $0.4 | |

---

**Total cost** = `$54.0 + Q × 0.5`\
where\
**Q** = # of rounded dowel pins\
**M** = # of cells in series\
If `M ≤ 8` then `Q = 4`; else, `Q = 8`

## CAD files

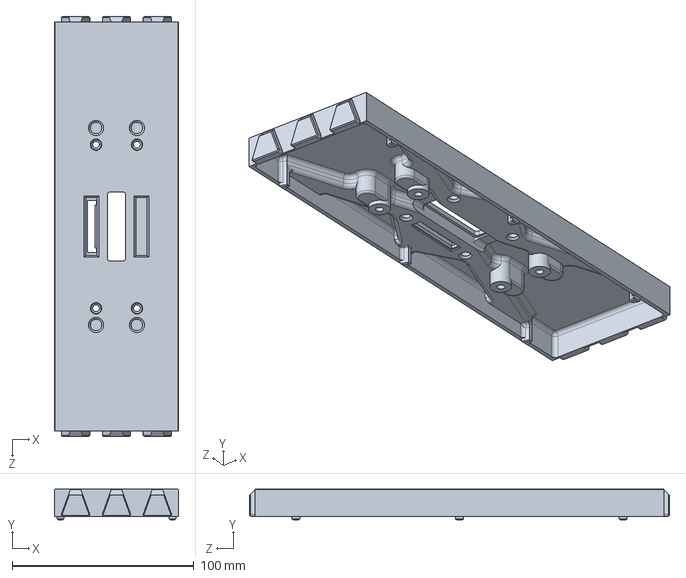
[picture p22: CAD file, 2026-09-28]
1_CAD_Files/21700_10s/21700_10s3p/Battery/Bottom_Plate/battery_bottom_plate_10s3p_v1.SLDPRT
68.2 x 17.0 x 231.0 mm

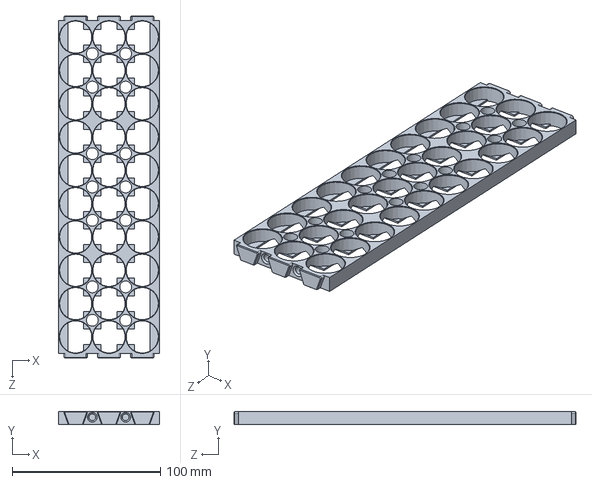
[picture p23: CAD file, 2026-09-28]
1_CAD_Files/21700_10s/21700_10s3p/Battery/Frame/battery_frame_10s3p.SLDPRT
68.2 x 9.00 x 231.0 mm

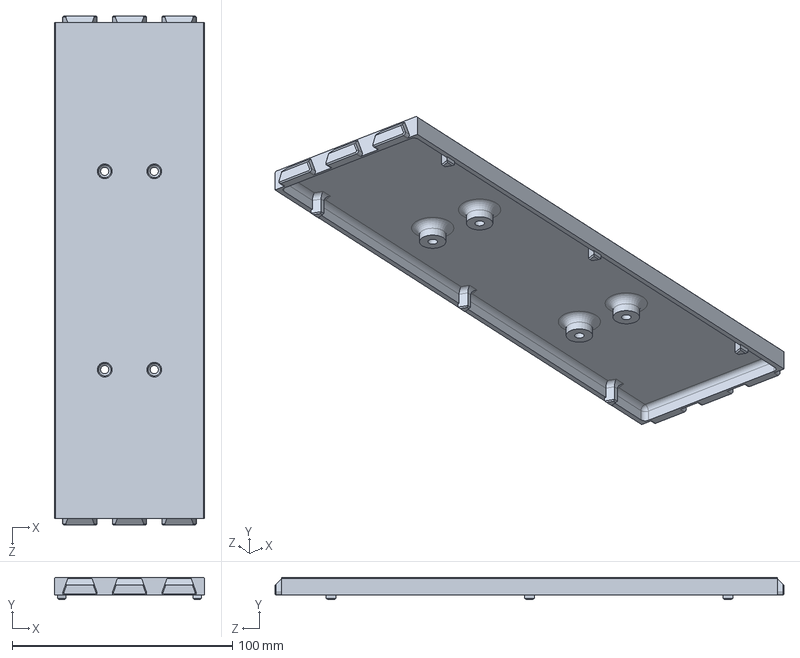
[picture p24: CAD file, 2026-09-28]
1_CAD_Files/21700_10s/21700_10s3p/Battery/Top_Plate/battery_top_plate_10s3p.SLDPRT
68.2 x 10.0 x 231.0 mm

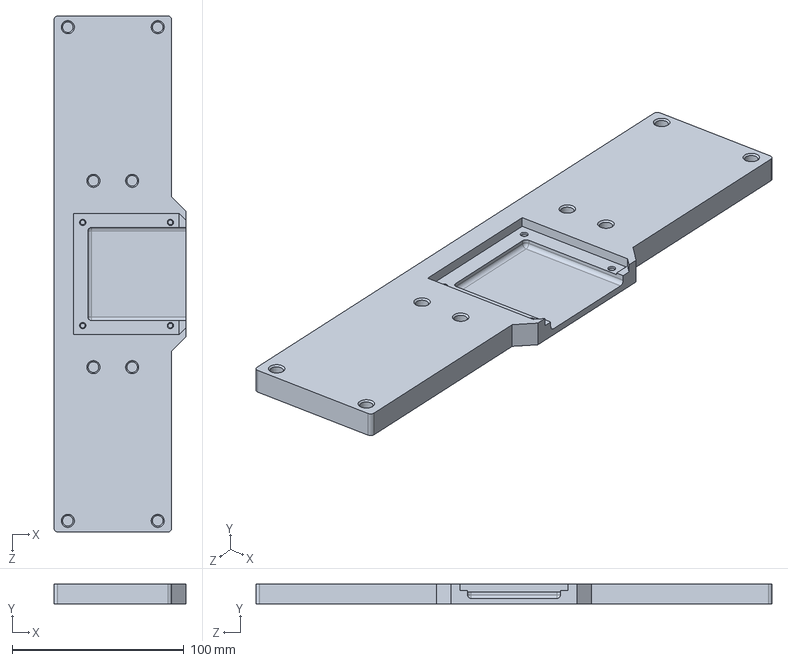
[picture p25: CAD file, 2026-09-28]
1_CAD_Files/21700_10s/21700_10s3p/Charging Station/charging_station_body_10s3p.SLDPRT
76.6 x 11.5 x 300.0 mm

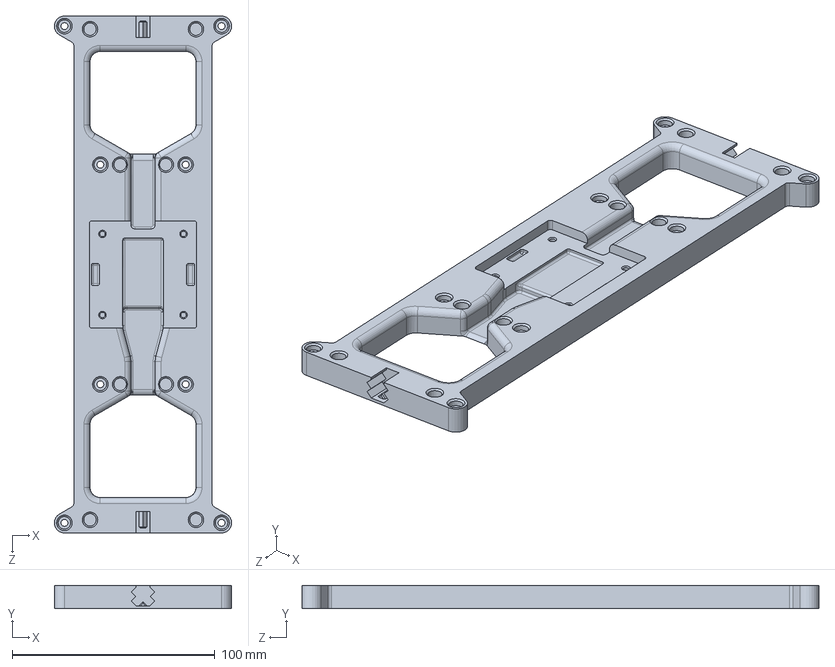
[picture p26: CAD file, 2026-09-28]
1_CAD_Files/21700_10s/21700_10s3p/Vehicle Adapter/vehicle_adapter_body_10s3p.SLDPRT
87.5 x 11.5 x 255.0 mm

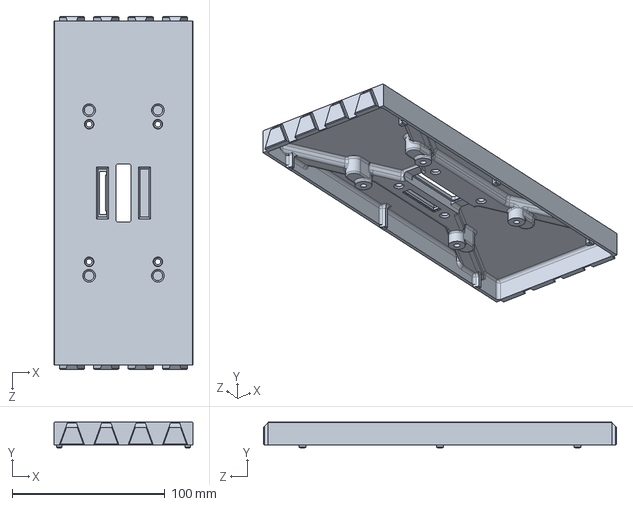
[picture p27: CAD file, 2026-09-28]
1_CAD_Files/21700_10s/21700_10s4p/Battery/Bottom_Plate/battery_bottom_plate_10s4p_v1.SLDPRT
90.8 x 17.0 x 231.0 mm

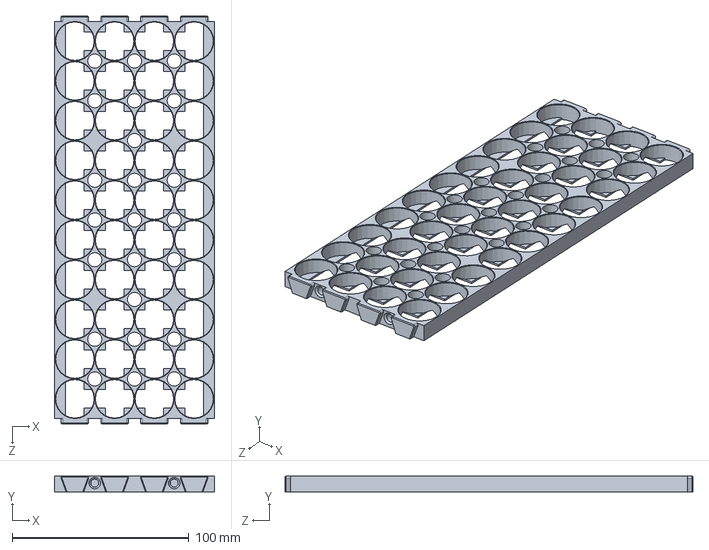
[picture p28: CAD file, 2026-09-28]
1_CAD_Files/21700_10s/21700_10s4p/Battery/Frame/battery_frame_10s4p.SLDPRT
90.8 x 9.00 x 231.0 mm

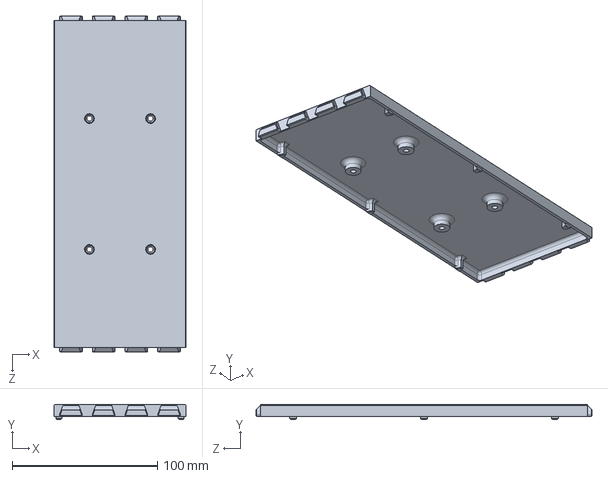
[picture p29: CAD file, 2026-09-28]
1_CAD_Files/21700_10s/21700_10s4p/Battery/Top_Plate/battery_top_plate_10s4p.SLDPRT
90.8 x 10.0 x 231.0 mm

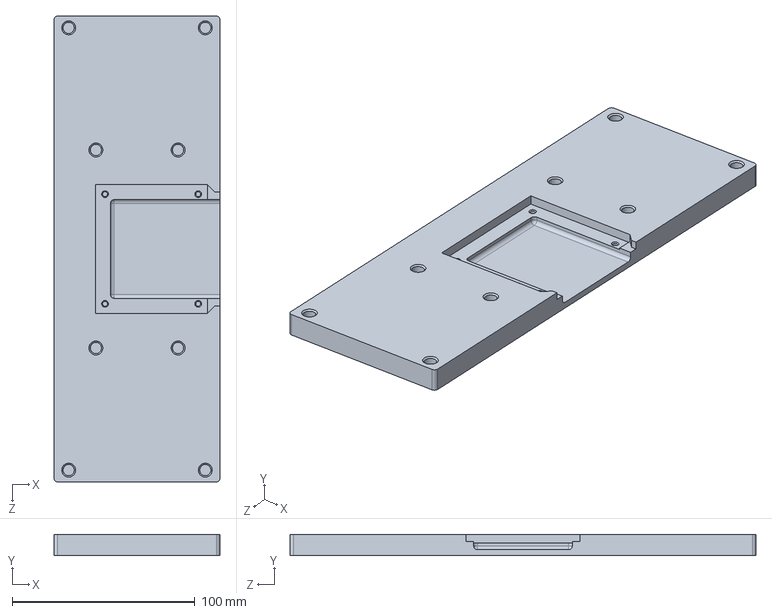
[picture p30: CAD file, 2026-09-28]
1_CAD_Files/21700_10s/21700_10s4p/Charging_Station/charging_station_body_10s4p.SLDPRT
90.8 x 11.5 x 255.0 mm

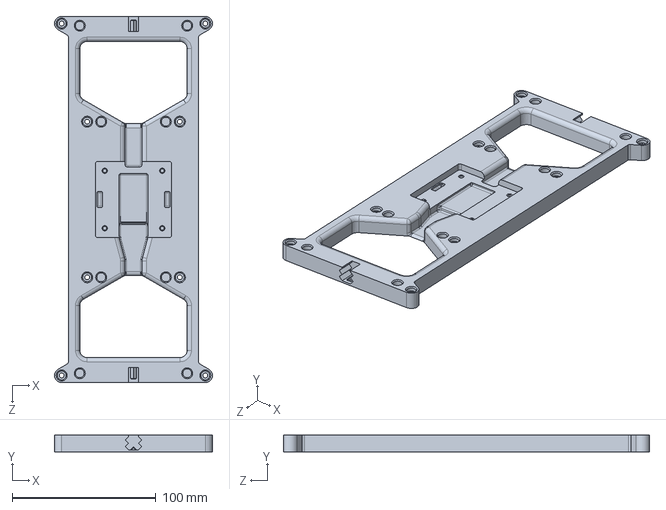
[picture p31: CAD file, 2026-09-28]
1_CAD_Files/21700_10s/21700_10s4p/Vehicle_Adapter/vehicle_adapter_body_10s4p.SLDPRT
110.0 x 11.5 x 255.0 mm

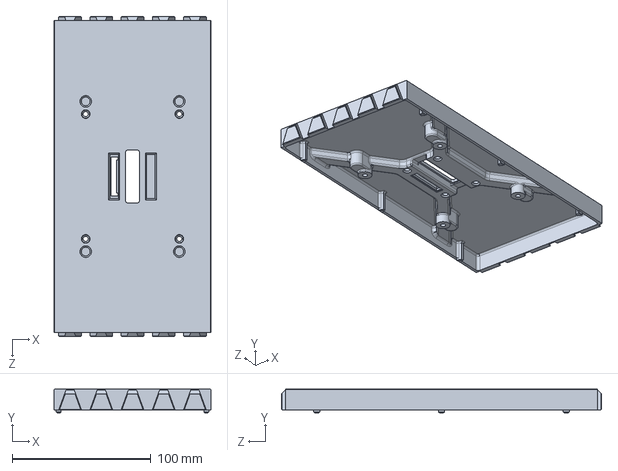
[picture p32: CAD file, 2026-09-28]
1_CAD_Files/21700_10s/21700_10s5p/Battery/Bottom_Plate/battery_bottom_plate_10s5p_v1.SLDPRT
113.2 x 17.0 x 231.0 mm

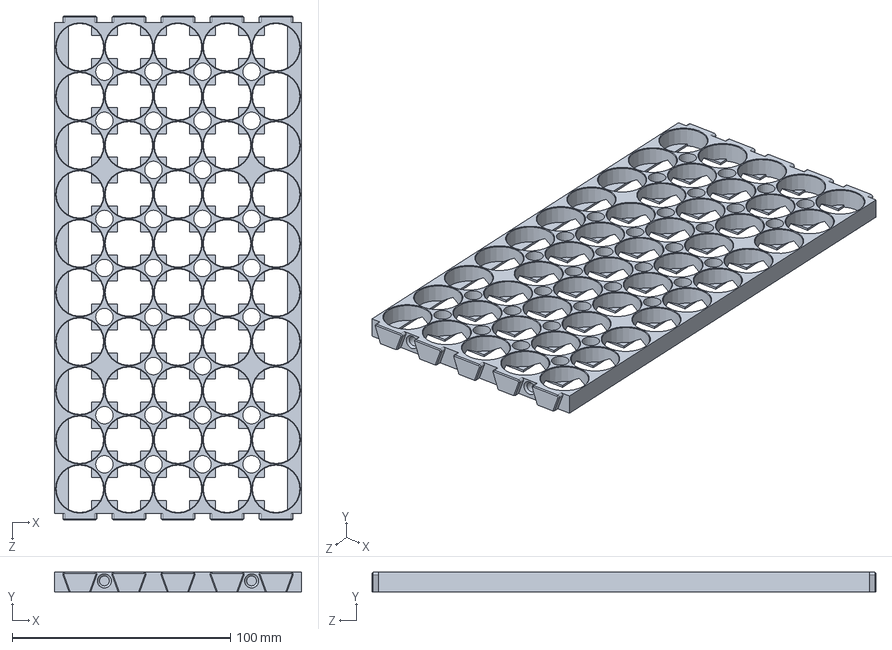
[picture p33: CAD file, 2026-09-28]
1_CAD_Files/21700_10s/21700_10s5p/Battery/Frame/battery_frame_10s5p.SLDPRT
113.2 x 9.00 x 231.0 mm

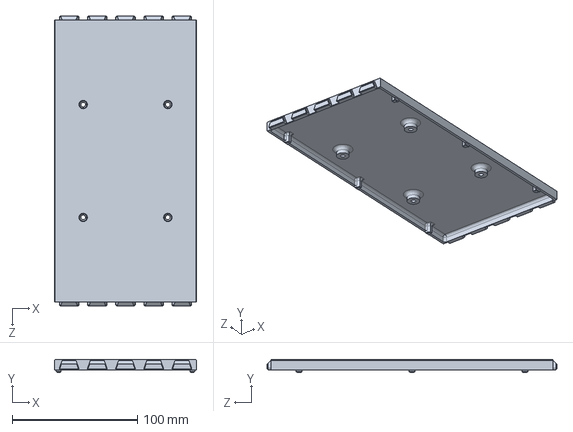
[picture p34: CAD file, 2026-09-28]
1_CAD_Files/21700_10s/21700_10s5p/Battery/Top_Plate/battery_top_plate_10s5p.SLDPRT
113.2 x 10.0 x 231.0 mm

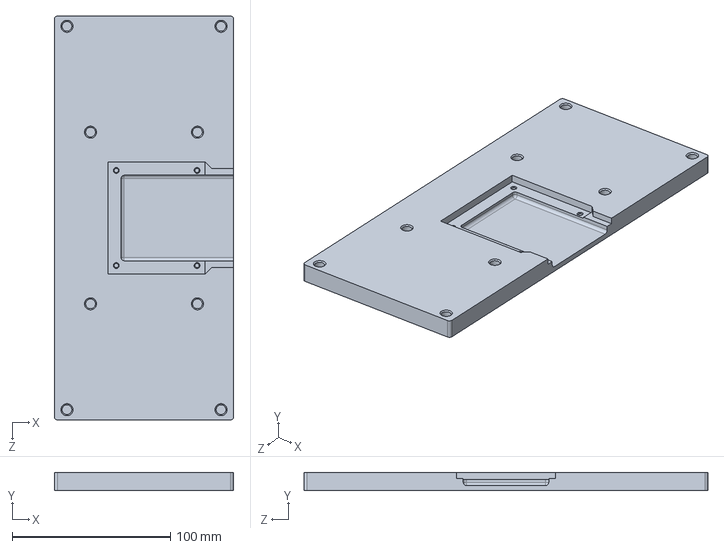
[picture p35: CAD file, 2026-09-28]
1_CAD_Files/21700_10s/21700_10s5p/Charging_Station/charging_station_body_10s5p.SLDPRT
113.2 x 11.5 x 255.0 mm

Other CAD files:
1_CAD_Files/21700_10s/21700_10s5p/Vehicle_Adapter/vehicle_adapter_body_10s5p.SLDPRT
1_CAD_Files/21700_10s/21700_10s6p/Battery/Bottom_Plate/battery_bottom_plate_10s6p_v1.SLDPRT
1_CAD_Files/21700_10s/21700_10s6p/Battery/Frame/battery_frame_10s6p.SLDPRT
1_CAD_Files/21700_10s/21700_10s6p/Battery/Top_Plate/battery_top_plate_10s6p.SLDPRT
1_CAD_Files/21700_10s/21700_10s3p/Battery/Bottom_Plate/battery_bottom_plate_10s3p_v1.STL
1_CAD_Files/21700_10s/21700_10s3p/Battery/Frame/battery_frame_10s3p.STL
1_CAD_Files/21700_10s/21700_10s3p/Battery/Top_Plate/battery_top_plate_10s3p.STL
1_CAD_Files/21700_10s/21700_10s3p/Charging Station/charging_station_body_10s3p.STL
1_CAD_Files/21700_10s/21700_10s3p/Vehicle Adapter/vehicle_adapter_body_10s3p.STL
1_CAD_Files/21700_10s/21700_10s4p/Battery/Bottom_Plate/battery_bottom_plate_10s4p_v1.STL
1_CAD_Files/21700_10s/21700_10s4p/Battery/Frame/battery_frame_10s4p.STL
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

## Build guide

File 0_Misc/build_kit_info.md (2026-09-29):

# DIY 21700 Battery System Kit Info
## Purpose
Kits are available to make the the build process easier: in essence, all you need to do upon receiving the kit is
1) Insert your favorite cells (purchased separately) into the fully-prepared 3D printed frames
2) spot weld the busbars to the cell terminals
3) Solder the balance cable wires to the busbars
4) Cut and solder the 8 AWG power wires to the battery PCB
5) fasten the fully-prepared 3D printed parts and pre-populated PCBs together with screws
6) Test the battery by performing a few charge/discharge cycles on your battery charger (the battery charger is not included in the kit)

Then, the tools required reduces to
1) a suitable spot welder
2) soldering iron
3) metric hex wrenches
4) a suitable battery charger

## What You Get
Each kit comes with:
* a prebuilt vehicle adapter
  <p align="left">
    
  </p>
  
* a prebuilt charging station
  <p align="left">
    
  </p>

* all parts needed to build the battery
  - frames
  - top plate
  - bottom plate
  - pre-built end plates
  - battery PCB
  - 8 AWG wires
  - 6mm bullet connectors
  - pre-wired JST-XH connectors
  - prepared busbars
  - 21700 insulator rings

* step-by-step instructions

> IMPORTANT NOTE: the kit **<ins>does NOT come with 21700 cells: you must select and purchase these on your own. Additionally, spot welding and hand soldering is required to build the battery</ins>**. Finally, please check that the vehicle adapter's mounting holes and wire passthroughs will work on your vehicle: check the dimensions [here](../5_Integration_and_Test_Instructions/1_Vehicle_Adapter_Integration_Instructions/vehicle_adapter_integration_instructions.md).

## Pricing
For a battery system configuration given by
**M**s**N**p\
where\
**M** = number of cells in series\
**N** = number of cells in parallel

Then, the pricing scheme is as follows:\
Total price = $5 * **M** * **N**

The table below shows the kit price according to configuration:

|| 6s | 8s | 10s | 12s |
| :--- | :--- | :--- | :--- | :--- |
| 3p | $90 | $120 | $150 | $180 |
| 4p | $120 | $160 | $200 | $240 |
| 5p | $150 | $200 | $250 | $300 |
| 6p | $180 | $240 | $300 | $360 |

## Ordering Info
The e-commerce site for purchasing kits is still being developed and should be ready by early October 2026. However, if you are interested in buying a kit, please send an email to **DIY21700BatterySystem@gmail.com** with the following:
* Subject line:\
  "**M**s**N**p Battery System Kit Interest"\
  where\
  **M** = number of cells in series\
  **N** = number of cells in parallel
  
* Body:\
  "Please notify me when this kit is available"

I will try to respond to these inquiries as soon as possible.

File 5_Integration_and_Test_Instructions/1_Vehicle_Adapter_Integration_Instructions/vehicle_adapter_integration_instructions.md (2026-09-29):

# Vehicle Adapter Integration Instructions
1. Use a CNC machine or drill press to cut out the vehicle adapter's mounting holes and wire pass-throughs in the material the vehicle adapter will be mounted on. The following table contains links to the vehicle adapter mounting hole and wire pass-through dimensions for each configuration.

   || 6s | 8s | 10s | 12s |
   | :--- | :--- | :--- | :--- | :--- |
   | 3p | [6s3p](Images/6s3p_vehicle_adapter_dimensions.png) | [8s3p](Images/8s3p_vehicle_adapter_dimensions.png) | [10s3p](Images/10s3p_vehicle_adapter_dimensions.png) | [12s3p](Images/12s3p_vehicle_adapter_dimensions.png) |
   | 4p | [6s4p](Images/6s4p_vehicle_adapter_dimensions.png) | [8s4p](Images/8s4p_vehicle_adapter_dimensions.png) | [10s4p](Images/10s4p_vehicle_adapter_dimensions.png) | [12s4p](Images/12s4p_vehicle_adapter_dimensions.png) |
   | 5p | [6s5p](Images/6s5p_vehicle_adapter_dimensions.png) | [8s5p](Images/8s5p_vehicle_adapter_dimensions.png) | [10s5p](Images/10s5p_vehicle_adapter_dimensions.png) | [12s5p](Images/12s5p_vehicle_adapter_dimensions.png) |
   | 6p | [6s6p](Images/6s6p_vehicle_adapter_dimensions.png) | [8s6p](Images/8s6p_vehicle_adapter_dimensions.png) | [10s6p](Images/10s6p_vehicle_adapter_dimensions.png) | [12s6p](Images/12s6p_vehicle_adapter_dimensions.png) |

   **Note that it is <ins>critically important to check that the battery will fit on your vehicle</ins>:** if the mount hole positions are wider/longer than your vehicle, then either
   
   * select a different battery configuration\
     or...
   * open the CAD file and reposition the mount holes, then 3D print the new vehicle adapter
   
2. Use M3 bolts and either M3 nylock nuts or M3 clinching rivet nuts to bolt down the vehicle adapter to the vehicle

3. Size the 8 AWG wires coming off the vehicle adapter board to the length required for connecting with the vehicle's power system, then solder on the XT90 connectors (female on battery side, male on vehicle side).

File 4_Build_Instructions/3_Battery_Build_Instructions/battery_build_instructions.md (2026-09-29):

# Battery Build Instructions

## Outline
1. 3D Print the Parts
2. Assemble the End Plates
3. Calculate Battery Busbar Size & Quantity
4. Prepare the Busbars
5. Place Cells in Frames & Spot Weld Busbars to Cells
6. Wire-up the Power & Balance Connectors
7. Attach Bottom, Top, & End Plates
8. Battery Cell Voltage Check & First Charge-up

---

## 1) 3D Print the Parts

| Part | Quantity | Filament | Print Settings |
| :--- | :--- | :--- | :--- |
| Frame| 2 | black ASA | 100% infill |
| Top plate | 1 | black ASA | 15% infill |
| Bottom plate | 1 | black ASA | 15% infill, requires supports |
| End plate | 2 | black ASA | 15% infill |
| End plate cover | 2 | black ASA | 15% infill, requires supports |
| End plate clamp | 4 | white ASA | 100% infill, requires supports |
| End plate button | 2 | white ASA | 15% infill |

---

## 2) Assemble the End Plate

2.1) Using metal shears, cut the arms of the two torsion springs to length of 15mm, as measured from the center of the coil: mark the spot on each arm with pen, then cut.
<p align="center">
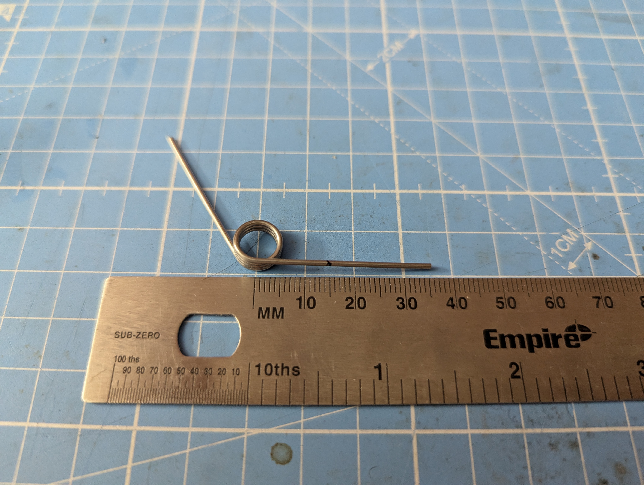
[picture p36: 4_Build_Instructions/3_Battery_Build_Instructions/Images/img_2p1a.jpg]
  
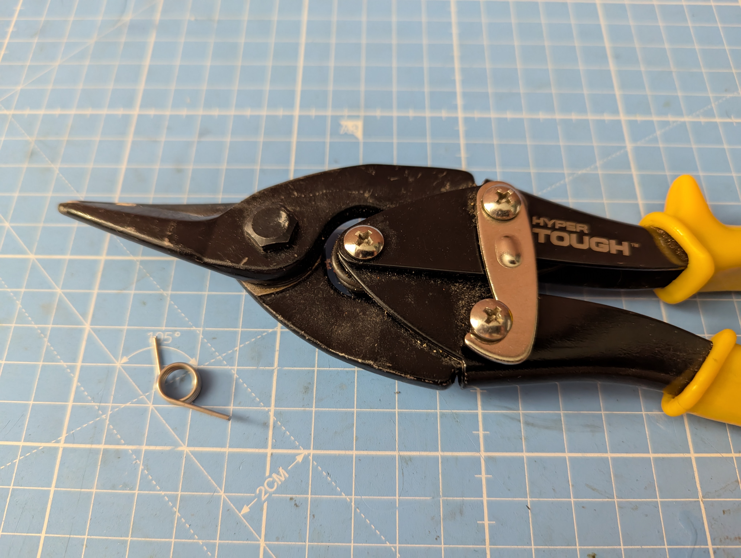
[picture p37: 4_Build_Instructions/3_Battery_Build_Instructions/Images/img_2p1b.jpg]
  
</p>

2.2) Assemble the spring, small dowel pin, & 3D printed clamp in the configuration shown in the image; do this twice.
<p align="center">
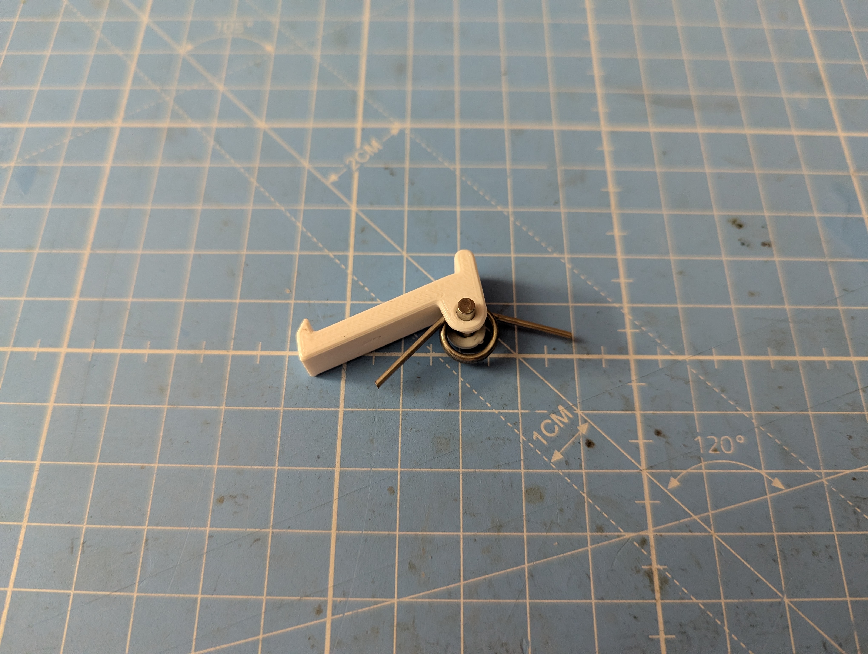
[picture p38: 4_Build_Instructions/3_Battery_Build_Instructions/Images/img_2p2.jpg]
  
</p>

2.3) Insert a M3×3mm×5mm brass threaded insert nut into the 3D-printed end plate near the square cutout.
<p align="center">
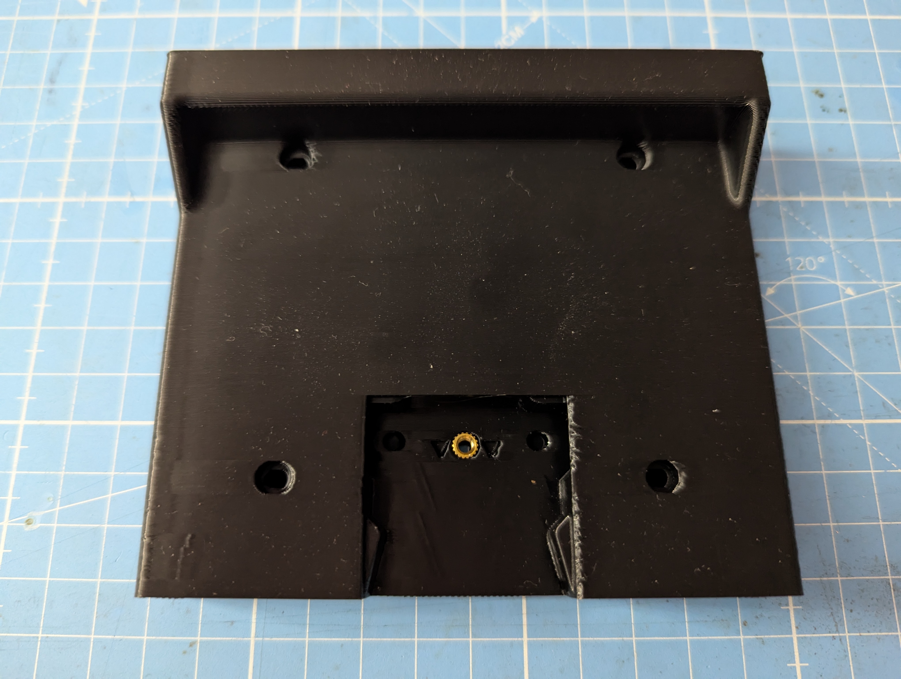
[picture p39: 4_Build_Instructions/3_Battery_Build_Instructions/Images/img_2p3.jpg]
  
</p>

2.4) Insert the 3D-printed button into the slot in the end plate.
<p align="center">
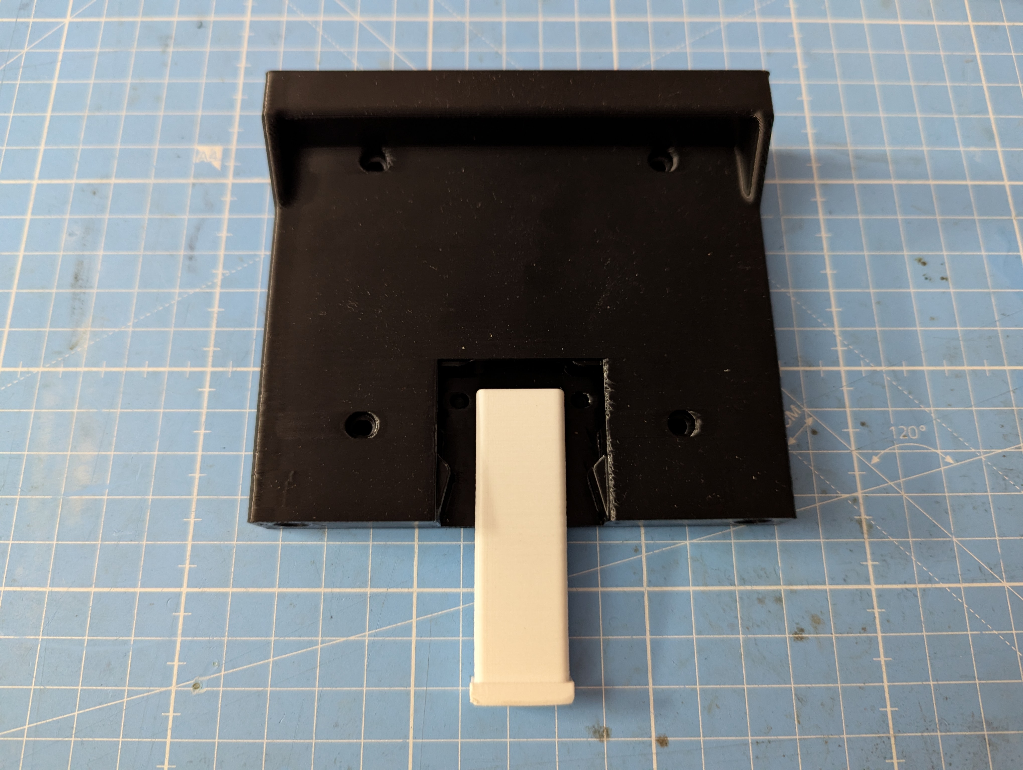
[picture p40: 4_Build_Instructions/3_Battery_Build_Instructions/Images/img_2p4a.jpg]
  
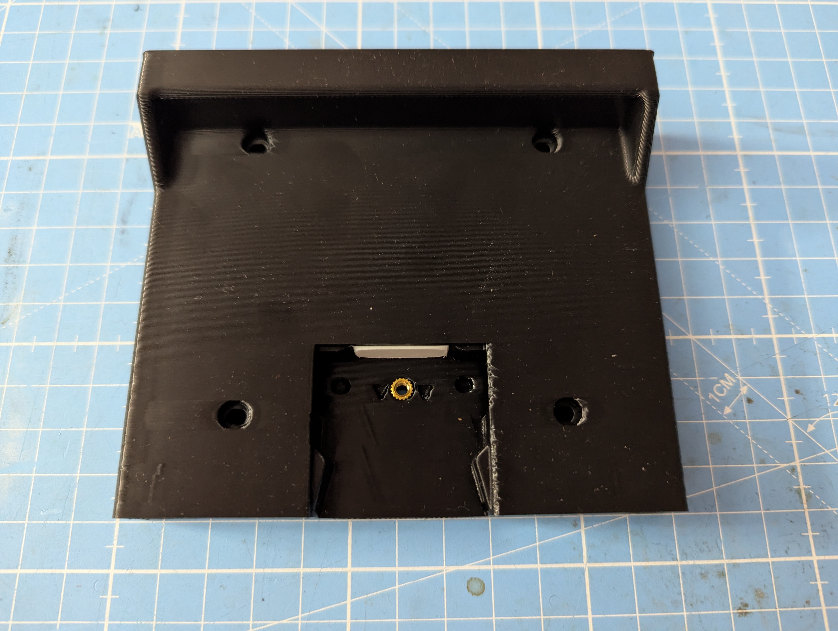
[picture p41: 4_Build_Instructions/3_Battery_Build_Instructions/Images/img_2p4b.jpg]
  
</p>

2.5) Insert the spring-dowel pin-clamp assemblies into the square cutout on the end plate. Note: if using a 3p end plate, must complete the battery build then fasten the end plate to the battery using two M3×16mm & two M3×5mm bolts before doing this step.
<p align="center">
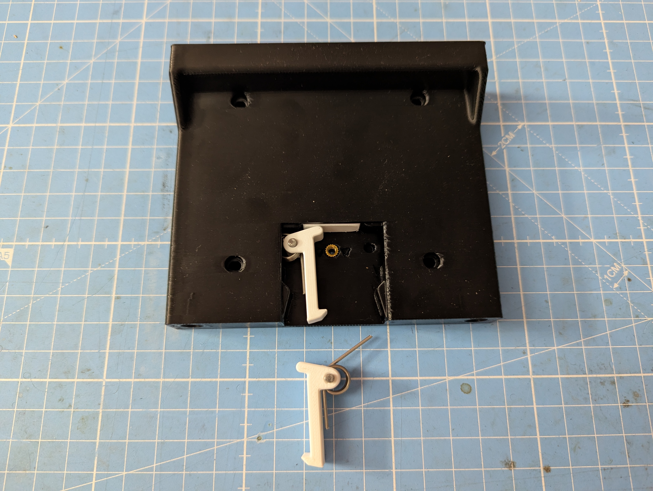
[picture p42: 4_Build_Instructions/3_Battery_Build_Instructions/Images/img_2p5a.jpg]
  
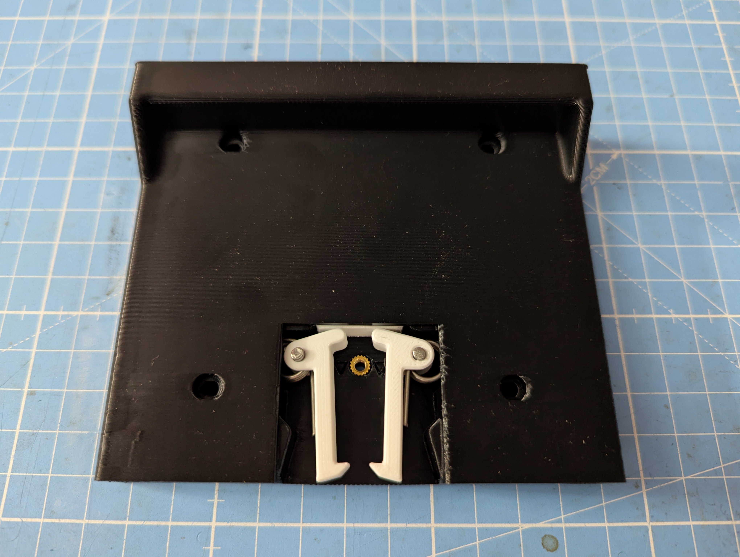
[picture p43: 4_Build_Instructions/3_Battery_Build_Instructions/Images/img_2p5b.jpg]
  
</p>

2.6) Place 3D-printed cover over the square cutout, & fasten using M3×12mm bolt.
<p align="center">
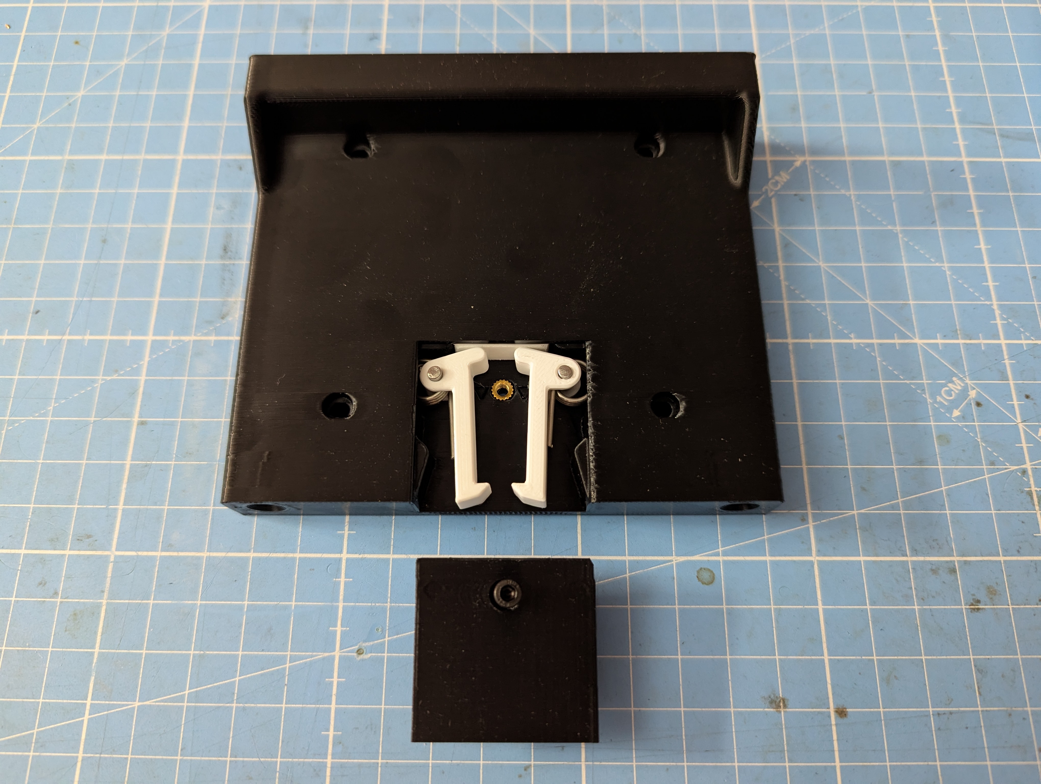
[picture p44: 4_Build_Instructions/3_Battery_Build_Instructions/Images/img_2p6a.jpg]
  
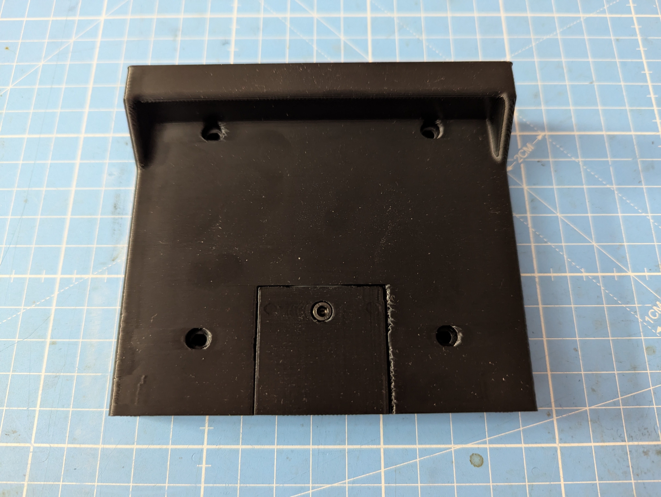
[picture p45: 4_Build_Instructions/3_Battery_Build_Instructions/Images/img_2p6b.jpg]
  
</p>

---

## 3) Calculate Battery Busbar Size & Quantity

With the battery configuration specified by $MsNp$ where:
- $M$ = # of cells in series
- $N$ = # of cells in parallel

Then, we can properly specify the size & quantity of busbars required for the battery. Each battery requires two $1 \times N$ busbars for the positive & negative terminals. Additionally, each battery requires a quantity of $M-1$ busbars of size $2 \times N$.

For example, A battery that has 8 cells in series & 5 cells in parallel has a 8s5p configuration, so $M=8$ & $N=5$.

Thus, the battery requires:
Two busbars having size of $1 \times N = 1 \times 5$
<p align="center">
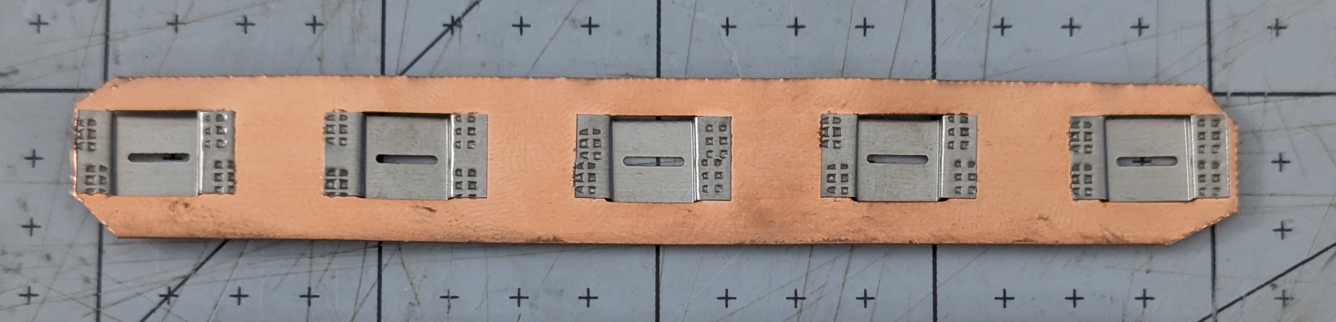
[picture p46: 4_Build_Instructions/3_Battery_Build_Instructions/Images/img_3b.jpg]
  
</p>

and busbars having size of $2 \times N = 2 \times 5$ in quantity of $M - 1 = 8 - 1 = 7$
<p align="center">
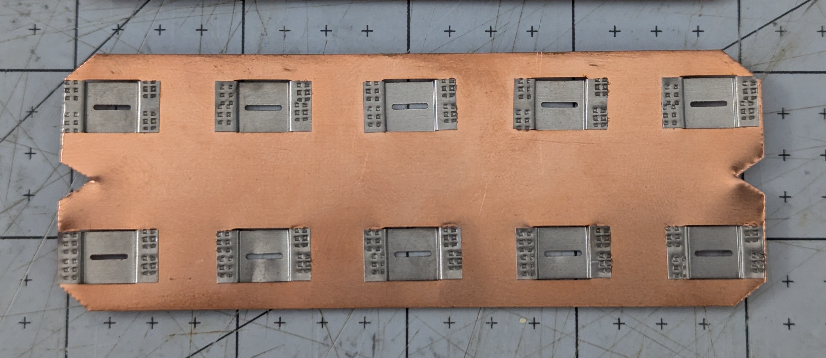
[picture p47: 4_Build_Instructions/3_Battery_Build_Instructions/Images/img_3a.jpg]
  
</p>

Finally, compute the total number of terminals on all busbars & then compute the number of busbar reels required (see BOM).

---

## 4) Prepare the Busbars

4.1) Cut out the busbars from the nickel-copper strip using metal shears. Each strip should terminate along the line where the nickel strips attach to the copper.
<p align="center">
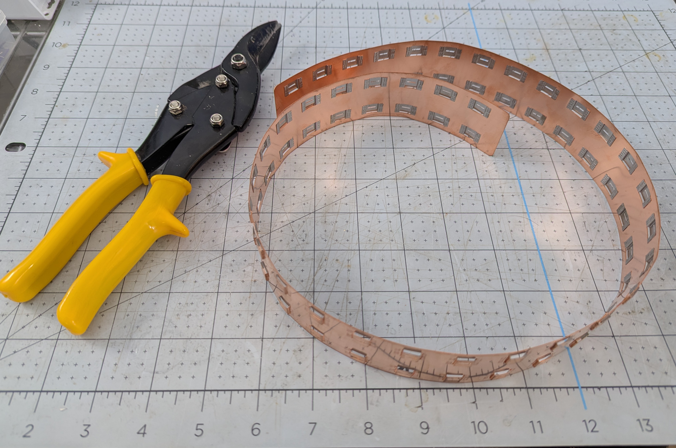
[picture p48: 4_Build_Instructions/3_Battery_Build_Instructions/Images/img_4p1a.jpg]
  
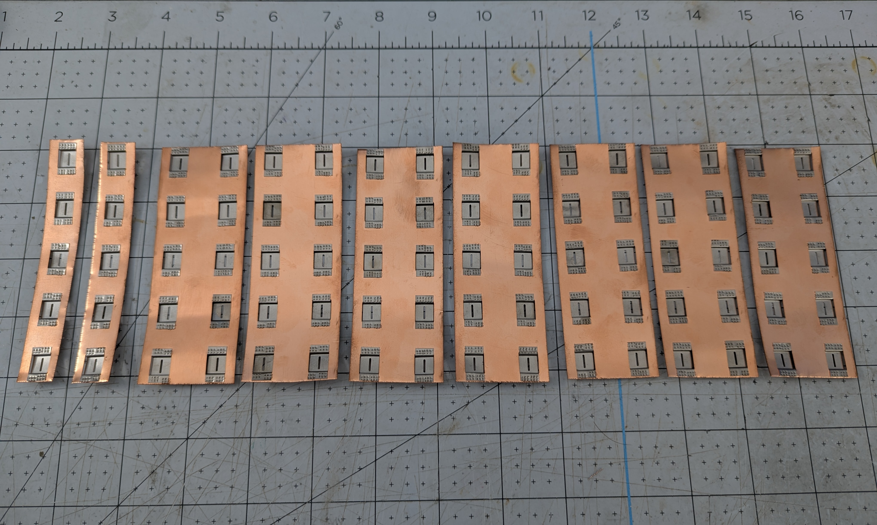
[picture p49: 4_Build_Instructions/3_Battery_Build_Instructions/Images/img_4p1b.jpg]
  
</p>

4.2) Cut off corners at 45° on each busbar & cut out notches approximately 4mm deep on either end of the wide busbars using metal shears.
<p align="center">
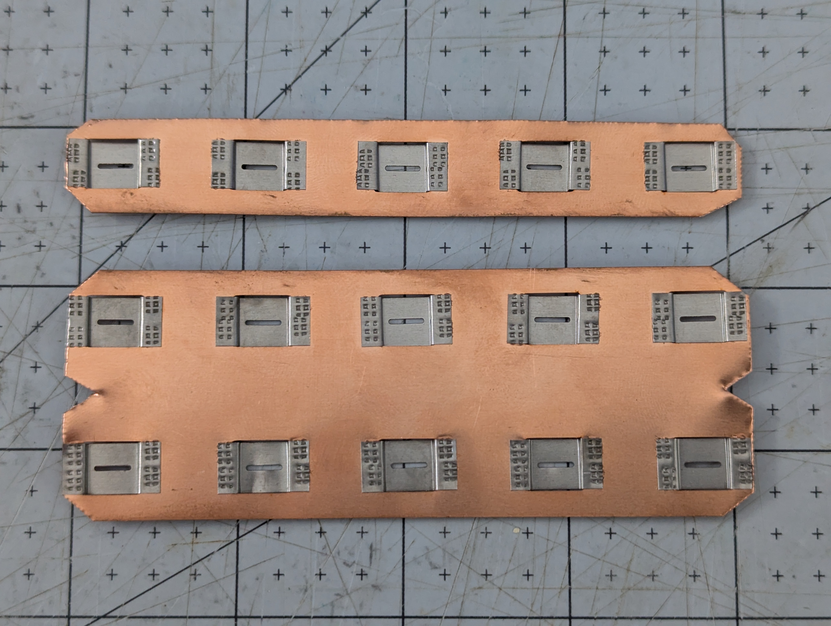
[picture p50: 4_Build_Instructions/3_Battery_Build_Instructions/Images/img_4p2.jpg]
  
</p>

4.3) Drill holes at the center of the four terminals at either end of each wide busbar using a hand drill or drill press with 5/16" or 8mm drill bit. First, mark the center-points on each busbar.
<p align="center">
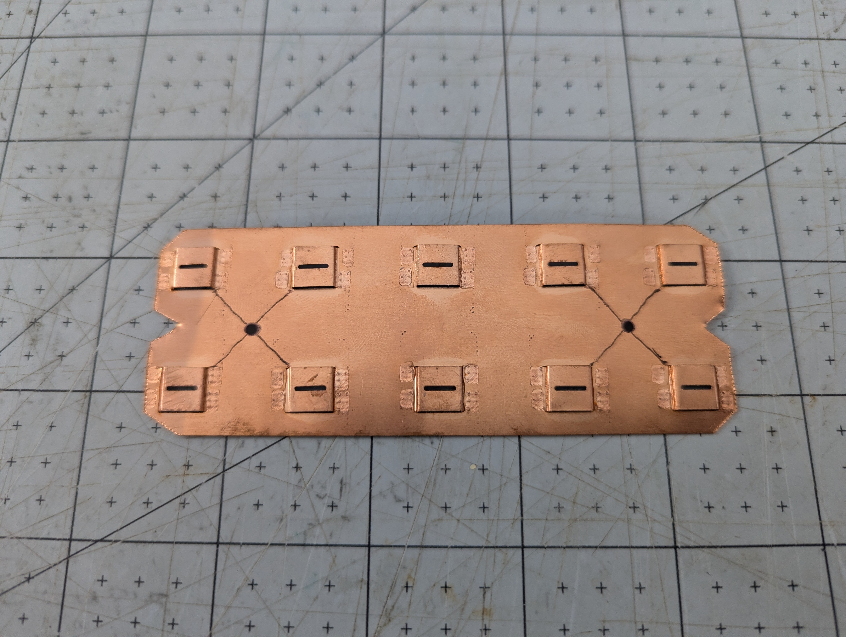
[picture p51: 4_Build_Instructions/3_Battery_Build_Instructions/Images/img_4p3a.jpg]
  
</p>

Then, attach busbars to a piece of scrap wood using double-sided tape (e.g. carpet tape).
<p align="center">
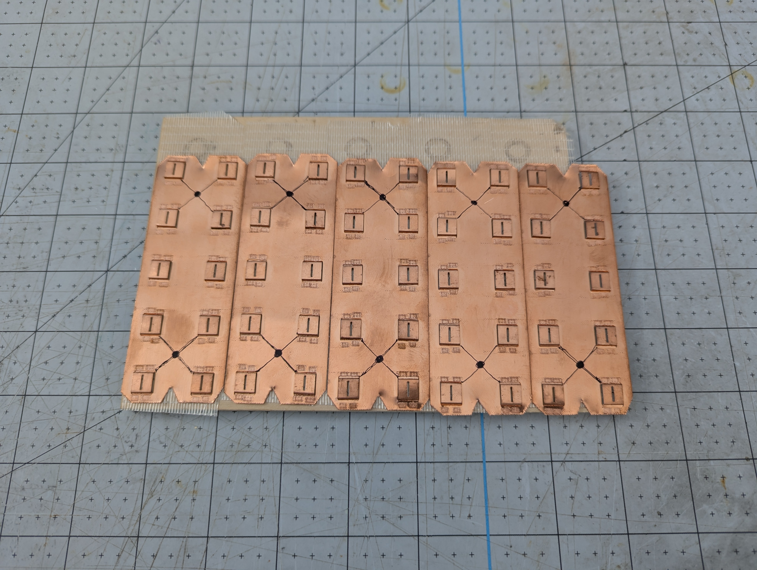
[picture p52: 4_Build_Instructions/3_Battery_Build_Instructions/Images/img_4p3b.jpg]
  
</p>

Finally, drill the holes through each busbar.
<p align="center">
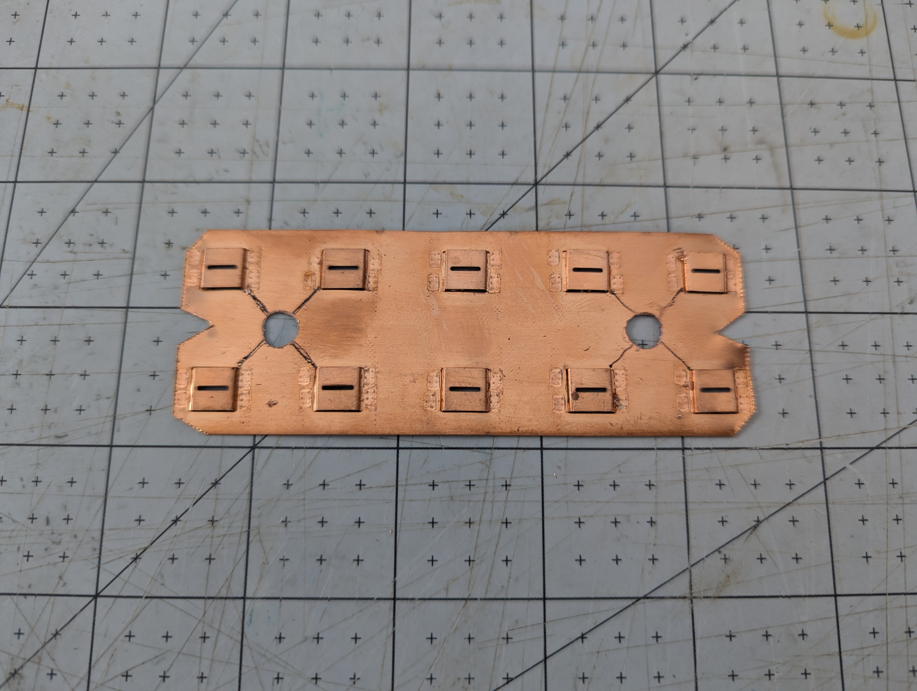
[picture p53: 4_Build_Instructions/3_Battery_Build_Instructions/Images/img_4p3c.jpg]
  
</p>

4.4) Solder 14 AWG solid copper wire along the edge of the narrow busbars.
<p align="center">
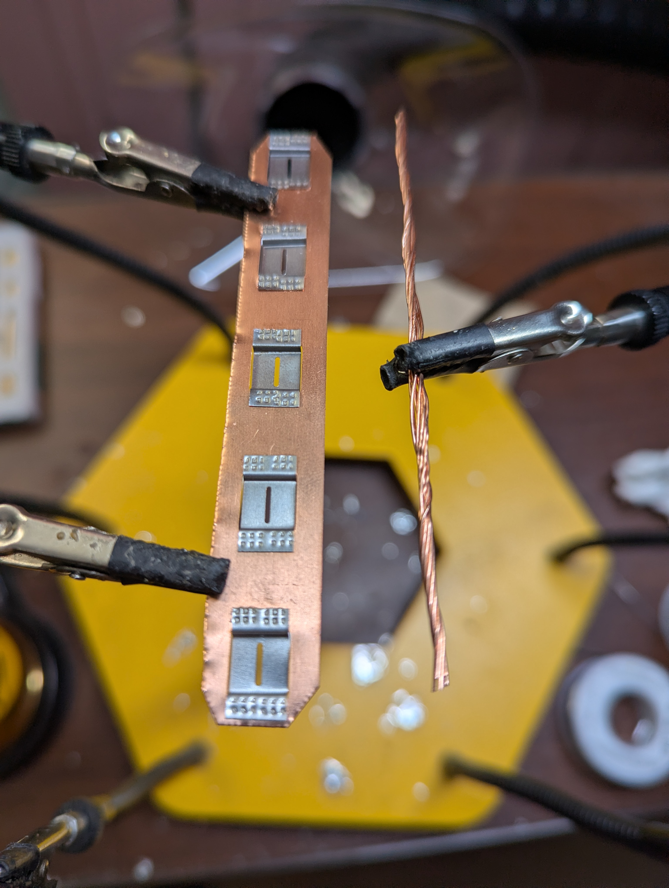
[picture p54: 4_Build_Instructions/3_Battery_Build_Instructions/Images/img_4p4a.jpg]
  
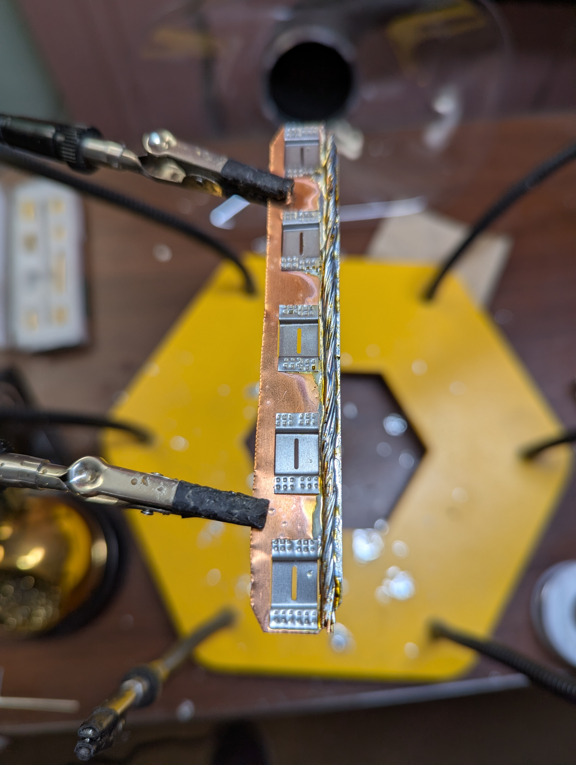
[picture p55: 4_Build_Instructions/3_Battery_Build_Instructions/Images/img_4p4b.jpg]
  
</p>

4.5) Solder female 6mm bullet connector to black & red 8 AWG wires having length of 40mm, then cover with shrink tube.
<p align="center">
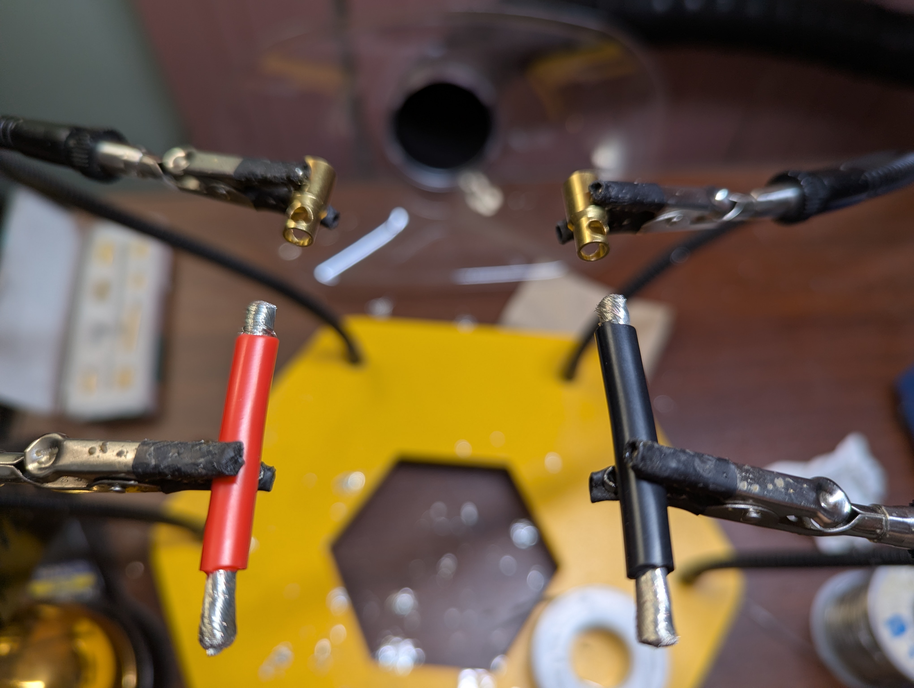
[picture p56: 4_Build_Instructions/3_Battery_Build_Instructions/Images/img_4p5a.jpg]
  
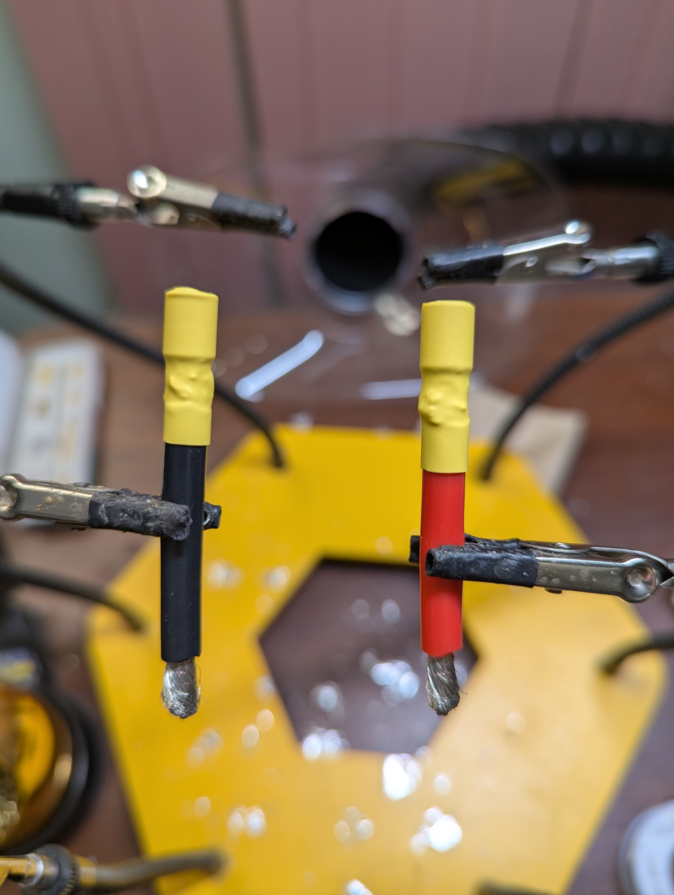
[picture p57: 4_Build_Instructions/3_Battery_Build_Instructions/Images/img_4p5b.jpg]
  
</p>

4.6) Solder 8 AWG wires with connectors to the narrow busbars: mimic the images below.
<p align="center">
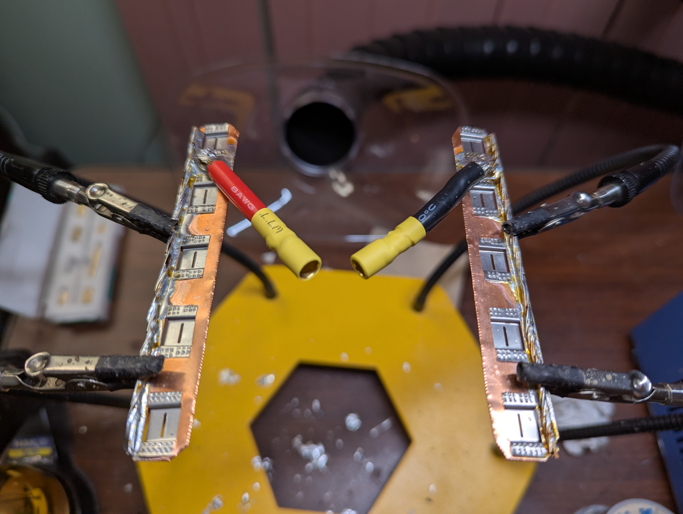
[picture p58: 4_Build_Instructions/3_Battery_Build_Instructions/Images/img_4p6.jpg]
  
</p>

---

## 5) Place Cells in Frames & Spot Weld Busbars to Cells

5.1) Insert eight M3×4mm×5mm brass insert nuts into each frame part: four on top surface & two on each end.
<p align="center">
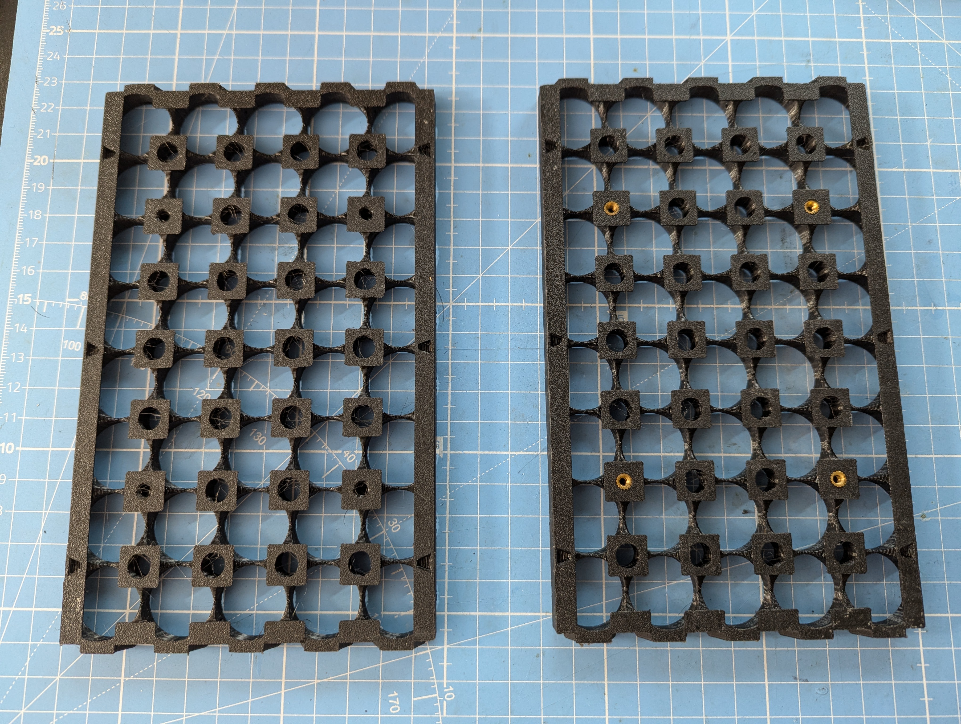
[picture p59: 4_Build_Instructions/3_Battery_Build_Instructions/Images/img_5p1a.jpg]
  
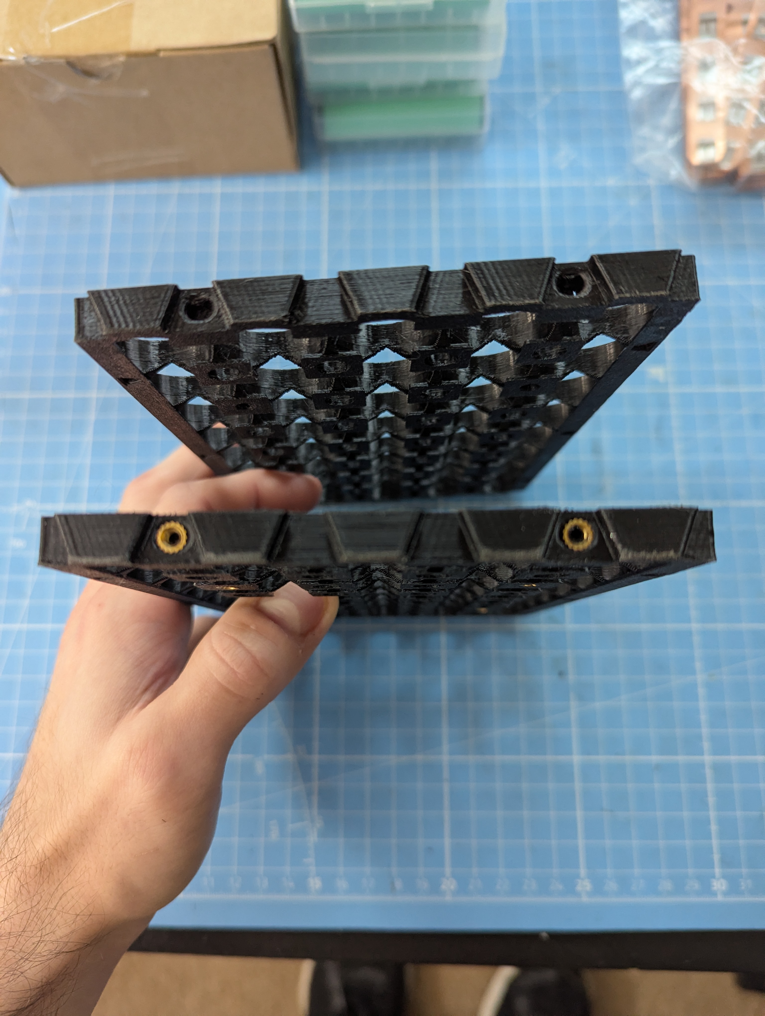
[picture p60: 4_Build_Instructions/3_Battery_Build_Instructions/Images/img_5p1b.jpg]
  
</p>

5.2) Put insulator rings on the positive terminals of all cells.
<p align="center">
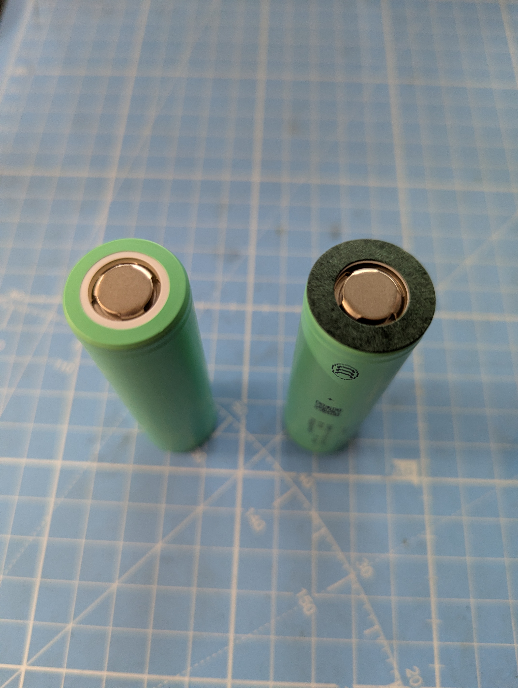
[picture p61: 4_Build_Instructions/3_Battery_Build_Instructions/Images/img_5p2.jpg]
  
</p>

5.3) Insert cells into one frame: alternate the polarity along the long edge.
<p align="center">
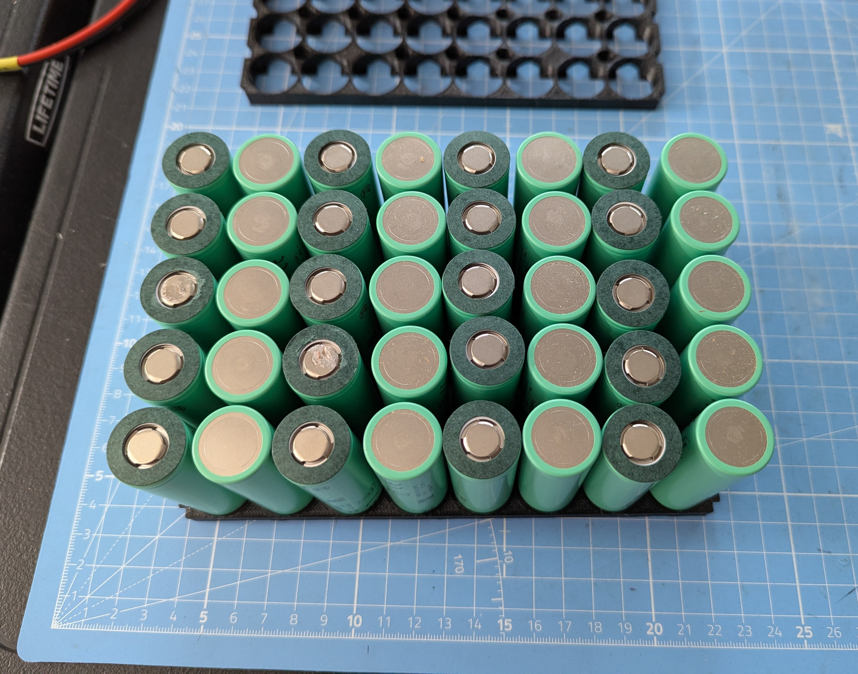
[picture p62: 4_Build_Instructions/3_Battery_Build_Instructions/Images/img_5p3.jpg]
  
</p>

5.4) Fit the other frame over the cells: use mallet to seat in place if necessary.
<p align="center">
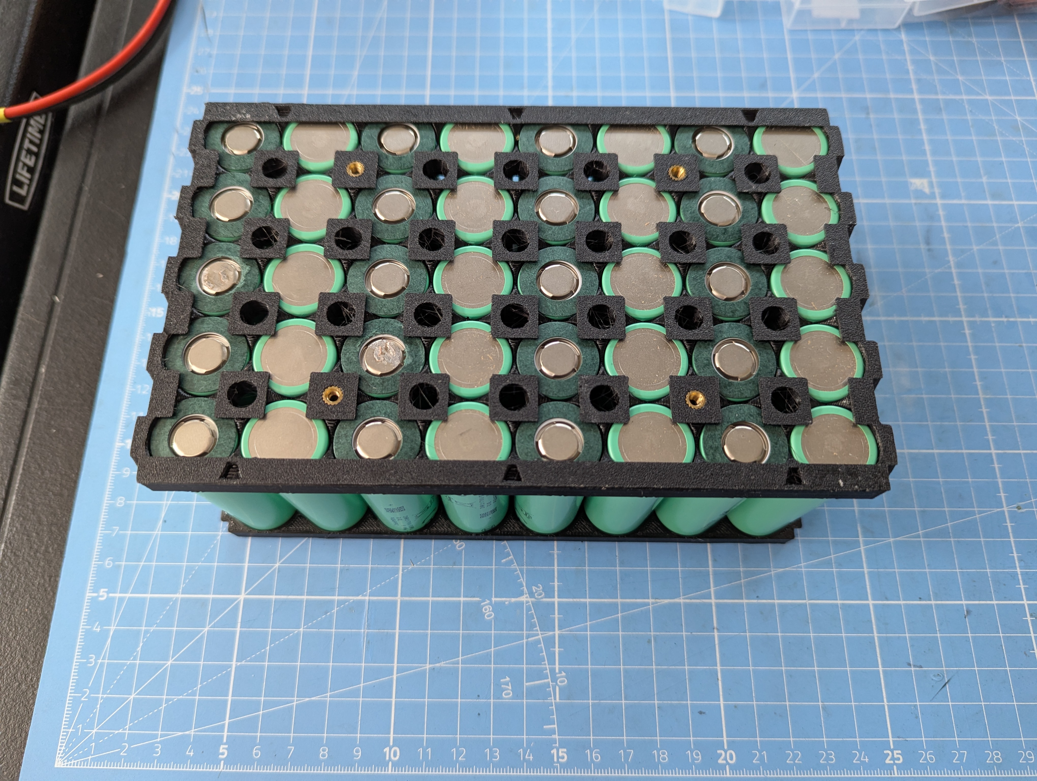
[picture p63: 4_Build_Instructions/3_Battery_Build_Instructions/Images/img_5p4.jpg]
  
</p>

5.5) Spot weld the wide busbars to the terminals: six spot welds per terminal is sufficient, with each spot weld pair made across the terminal cutout, not along it.
It helps to place dabs of super glue where the busbar makes contact with the plastic frame to hold the busbar in place.
<p align="center">
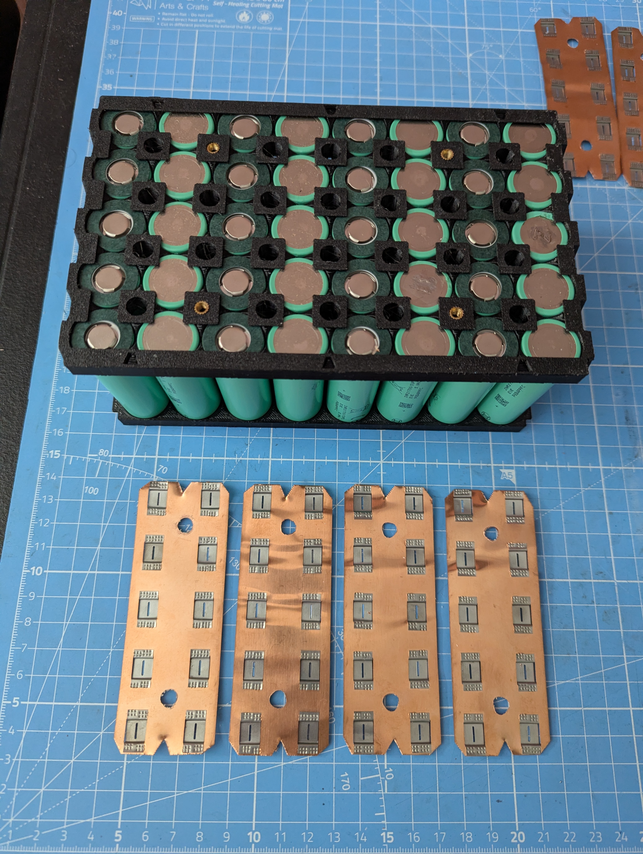
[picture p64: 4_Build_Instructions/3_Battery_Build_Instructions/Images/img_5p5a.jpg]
  
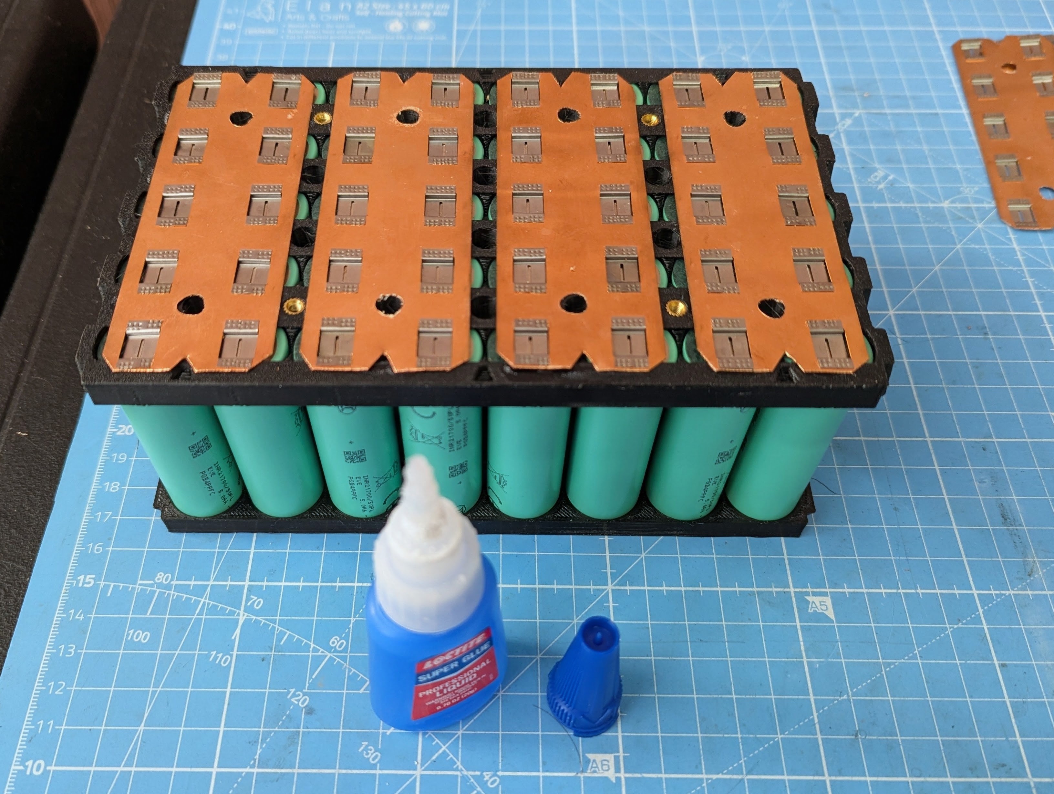
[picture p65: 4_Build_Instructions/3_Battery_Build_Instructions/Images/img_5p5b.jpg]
  
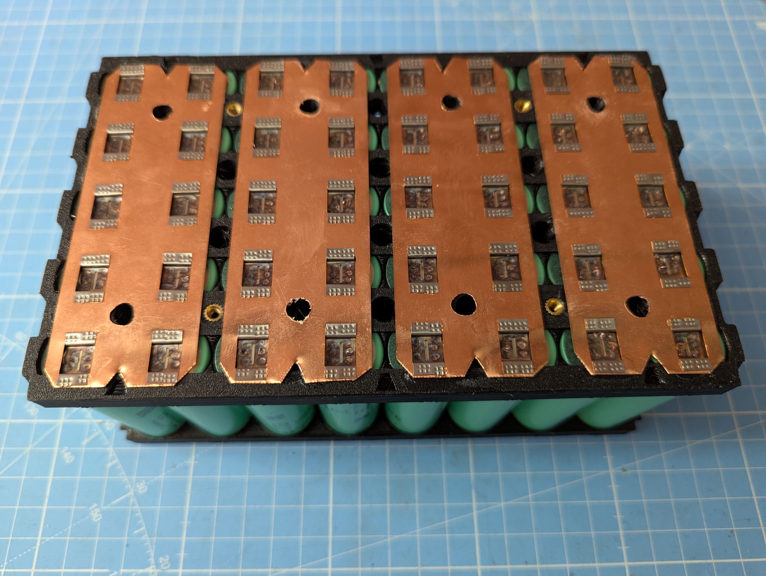
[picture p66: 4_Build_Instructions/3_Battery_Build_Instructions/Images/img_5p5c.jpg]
  
</p>

> **NOTICE:** Test your spot welder settings on scrap metal before attempting to spot weld the busbars, since failed welds can lead to destroying the entire busbar...
> <p align="center">
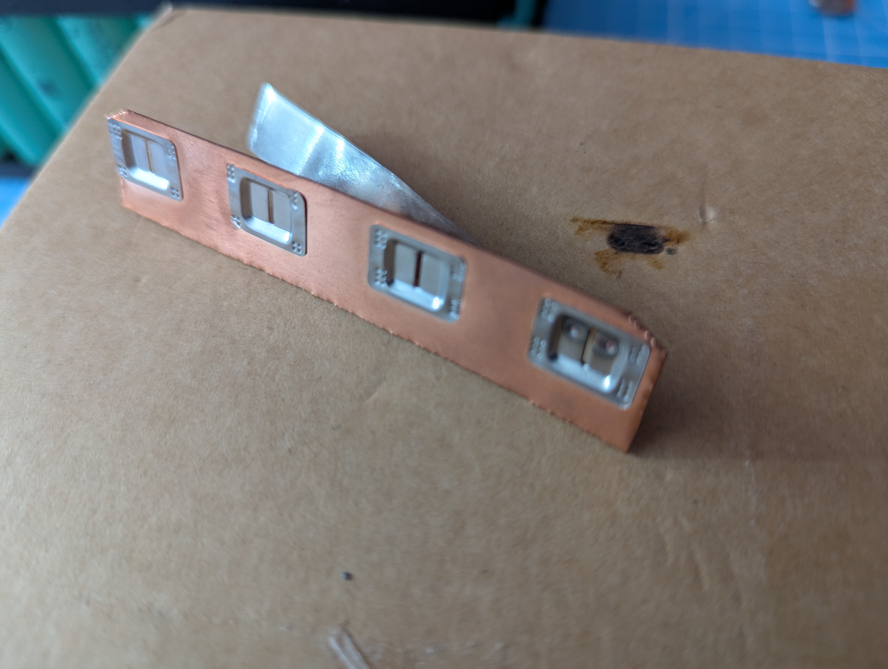
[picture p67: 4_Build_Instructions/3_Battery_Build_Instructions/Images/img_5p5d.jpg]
>  
> </p>
> 
> Do a tug test to make sure the weld is secure.
> <p align="center">
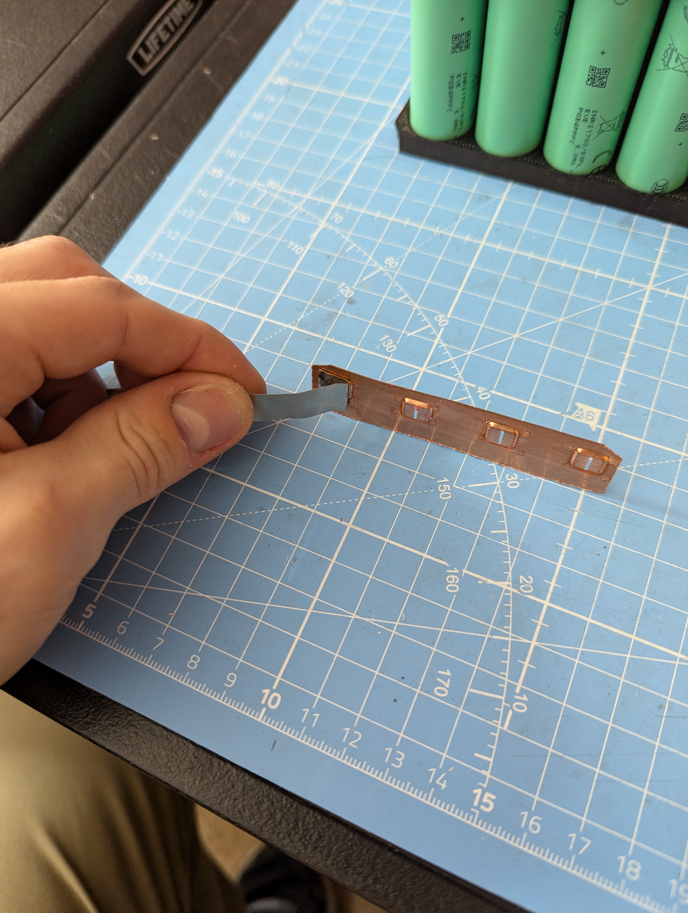
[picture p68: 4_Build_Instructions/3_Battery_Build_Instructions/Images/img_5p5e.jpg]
>  
> </p>

If you are using a battery-powered spot welder then I recommend that you charge up two batteries & switch off between them every ~60 welds to prevent them from overheating & exploding. Additionally, have a empty, sealable plastic container nearby: if the battery starts to swell, immediately unplug it, put it in the container, & take it outside for disposal.

Upon completion of this step, we can now define the side of the battery having only wide busbars as the "top side" of the battery.

5.6) Flip the battery over & place the thin busbars adjacent to their final positions: one with black wire near terminals with large exposed metal area, & one with red wire near terminals with insulator rings (see image).
<p align="center">
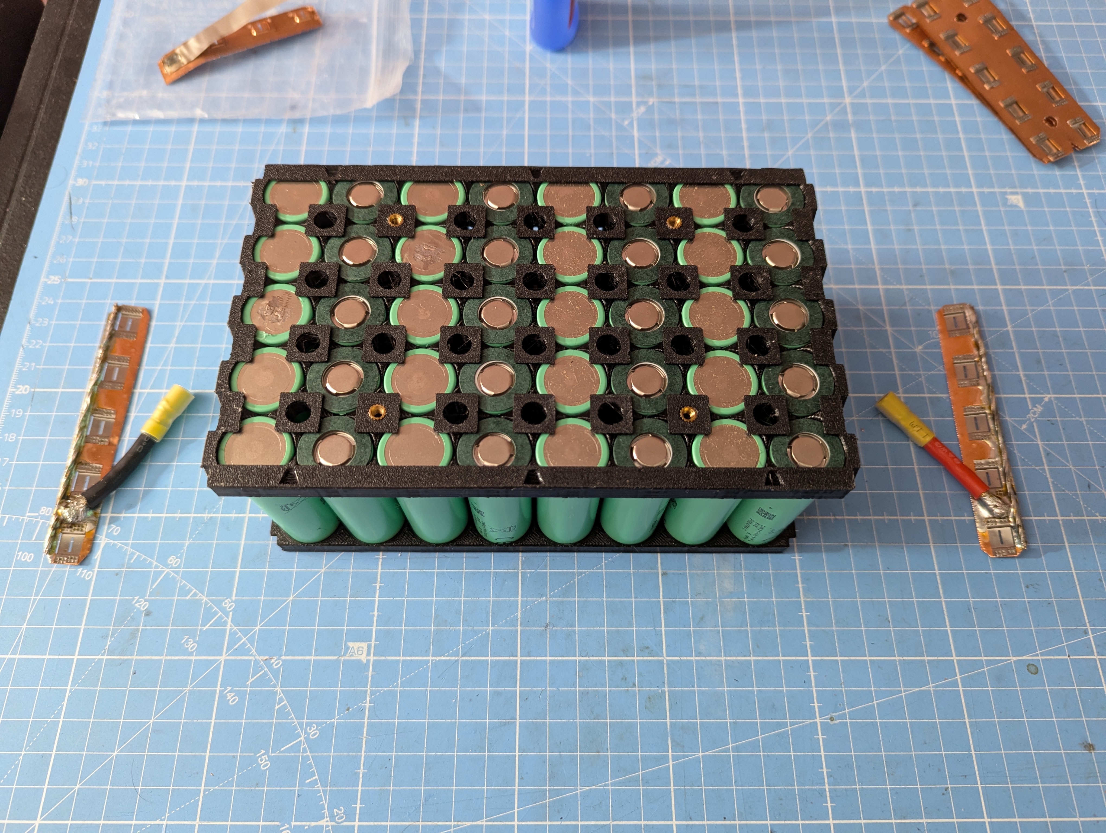
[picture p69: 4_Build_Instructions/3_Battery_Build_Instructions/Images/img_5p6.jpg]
  
</p>

5.7) Glue down the narrow busbars above their intended weld points: place glue on the plastic areas that make contact with the copper, NOT on the terminals! Be careful to not make contact with the adjacent parallel cells as this will short the battery!
<p align="center">
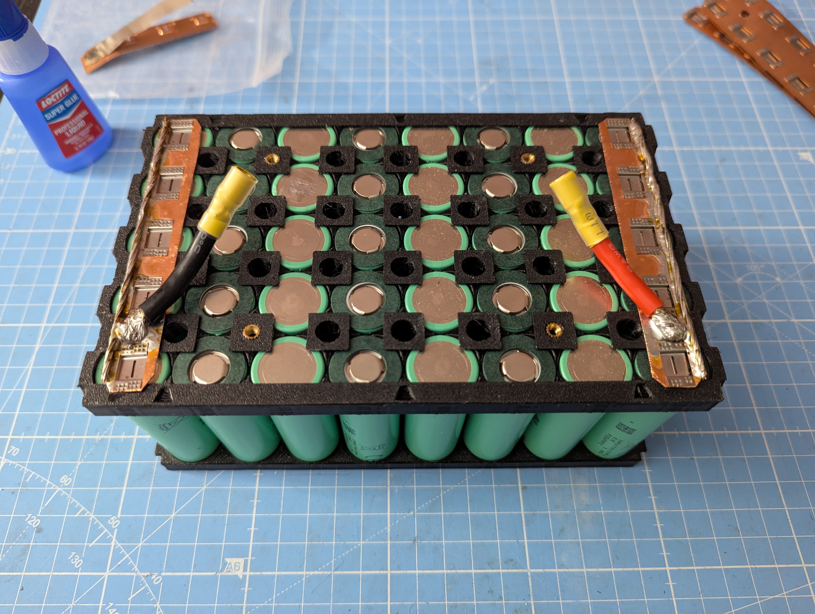
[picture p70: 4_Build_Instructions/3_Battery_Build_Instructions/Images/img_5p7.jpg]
  
</p>

5.8) Spot weld the narrow bus bars in place.
<p align="center">
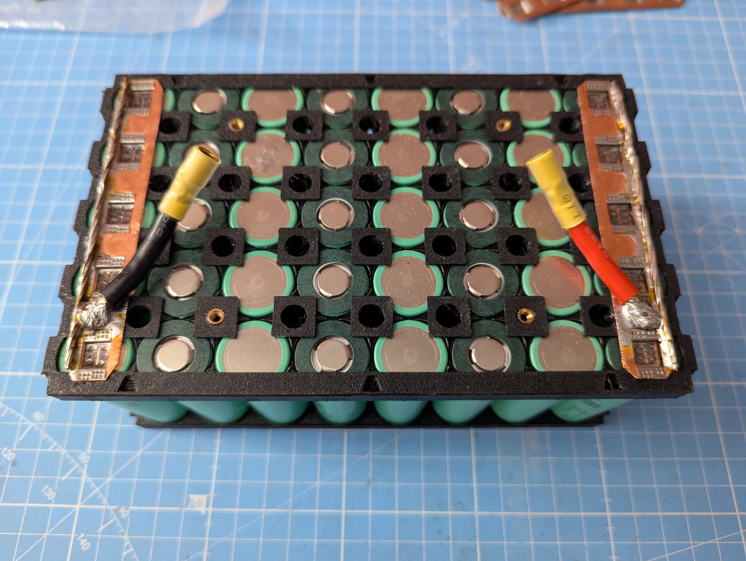
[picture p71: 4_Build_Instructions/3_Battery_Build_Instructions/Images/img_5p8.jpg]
  
</p>

5.9) Glue down the remaining wide busbars in the open slots between the thin busbars, being careful not to make contact with adjacent parallel cells.
<p align="center">
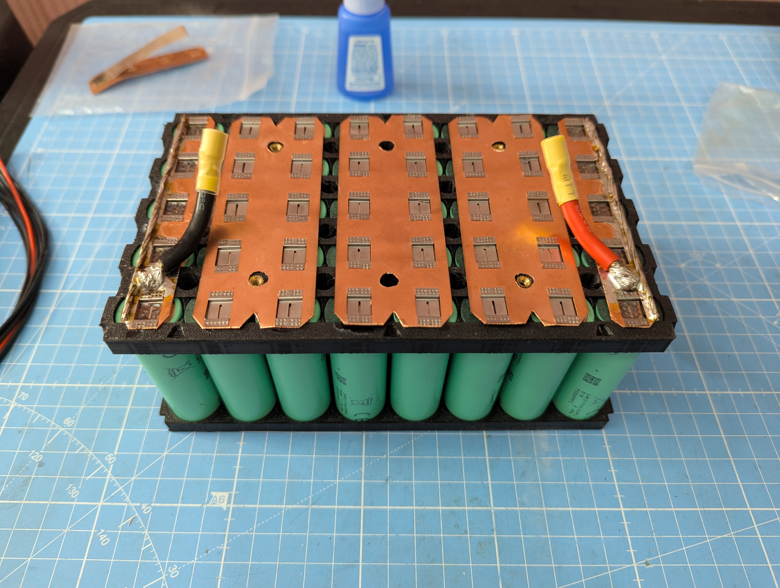
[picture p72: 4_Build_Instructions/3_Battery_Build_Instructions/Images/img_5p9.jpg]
  
</p>

5.10) Spot weld the remaining terminals.
<p align="center">
  
</p>

---

## 6) Wire-up the Power & Balance Connectors

6.1) Insert four threaded insert nuts into the bottom plate.
<p align="center">
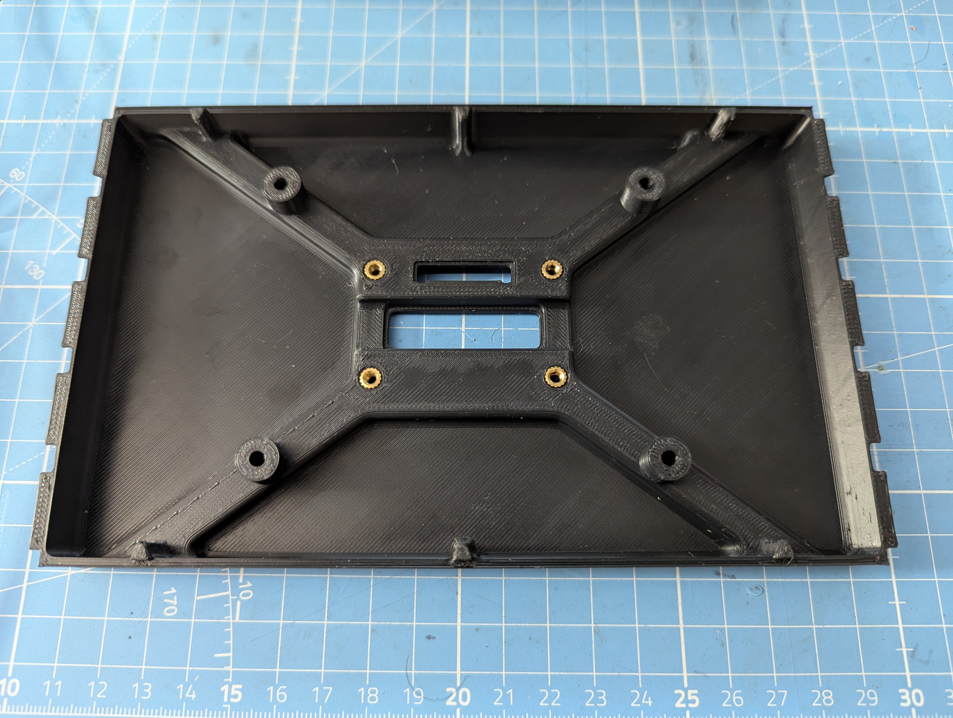
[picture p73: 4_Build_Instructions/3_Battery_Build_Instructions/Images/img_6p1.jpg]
  
</p>

6.2) Position the battery on the edge of the bottom plate in the orientation seen in the image.
<p align="center">
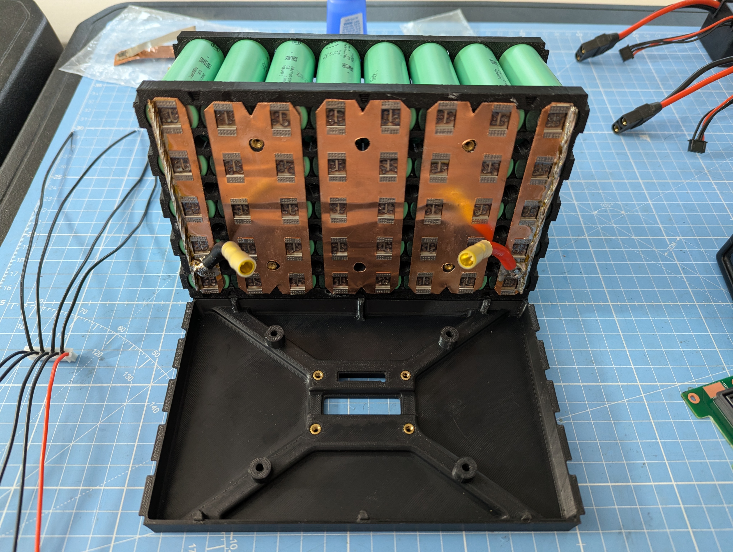
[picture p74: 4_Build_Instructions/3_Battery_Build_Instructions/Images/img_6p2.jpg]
  
</p>

6.3) Separate the wires on the JST-XH connector (see image).
<p align="center">
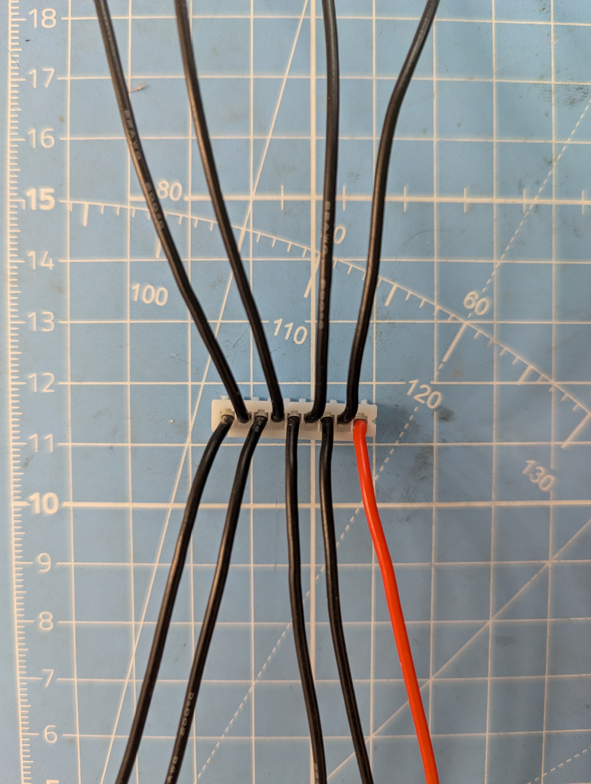
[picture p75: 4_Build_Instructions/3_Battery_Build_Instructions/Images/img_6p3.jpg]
  
</p>

6.4) With the red wire on the right, thread the upper wires through the holes along the bottom edge to the top side of the battery.
<p align="center">
  
  
</p>

6.5) Plug the JST-XH connector into its cutout in the bottom plate.
<p align="center">
  
</p>

6.6) Pull each wire connected to the JST-XH connector lying on the bottom plate toward its respective busbar, then cut, strip, & solder it to the busbar.

The solder points should be located below the bottom line of frame holes, with the wires oriented along the bottom edge (see image).
<p align="center">
  
</p>

6.7) With the battery still on the edge of the bottom plate, turn the battery around & solder the remaining balance wires to their respective terminals.
<p align="center">
  
</p>

6.8) Solder MISTA 12-pin female connector to the battery board.
<p align="center">
  
  
</p>

6.9) Mount the board with connector into the bottom plate. Note that the battery bottom plate must close with wires inside. Thus, for this to happen, the wires from the battery board must meet with those of the battery. In the mind's eye, project where the female bullet connectors on the battery wires would lie on the bottom plate if it were closed against the bottom of the battery. Then, cut an 8 AWG wire that extends from the battery board to this projected location, being mindful that the bullet connectors are aligned when connected.
<p align="center">
  
</p>

Then, cut the other wire using the length of this wire.

6.10) Solder male 6mm bullet connectors to the wires, then solder the wires to the battery board: red to Vbatt+, black to Vbatt-. Solder the wires to the battery board such that they are at a 45° angle from sticking straight out, angled toward the side of the board witho the notch in it.
<p align="center">
  
</p>

6.11) Using a multimeter, check continuity between the Vbatt+ terminal & Vbatt- terminal on the battery board. If no shorts found, then seat it in the bottom plate, secure with four M3×6mm screws, & plug it into the battery.
<p align="center">
  
</p>

---

## 7) Attach Bottom, Top, & End Plates

7.1) Fasten the bottom plate to the battery bottom frame using four M3×16mm bolts & fasten the top plate to the battery top frame using four M3×8mm bolts.
<p align="center">
  
</p>

7.2) Fasten the assembled end plates to the ends of the battery using eight M3×16mm bolts, with four bolts used per end plate.
<p align="center">
  
</p>

*This concludes the battery build*

---

## 8) Battery Cell Voltage Check & First Charge-up

8.1) Connect the charging station with a charger.
<p align="center">
  
</p>

8.2) Place battery on the charging station, then check that each cell voltage is near 3.5V. If not, must rework the balance cable wiring: check the wiring on the charging station, & if issue isn't there then check the wiring within the battery.
<p align="center">
  
</p>

8.3) If each cell shows nominal voltages, either run balance charging (i.e., charge each cell to 3.75V) if putting it in storage or run ordinary charging (i.e., charge each cell to 4.1V) for immediate use.

> **Warning:** Set the charger battery type to LiIon, not LiPo!

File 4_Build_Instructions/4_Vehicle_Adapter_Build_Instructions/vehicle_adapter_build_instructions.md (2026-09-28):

# Vehicle Adapter Build Instructions

## Outline
1. 3D Print the Parts
2. Assemble the Vehicle Adapter Board
3. Assemble the Vehicle Adapter

---

## 1) 3D Print the Parts

| Part | Quantity | Filament | Print Settings |
| :--- | :--- | :--- | :--- |
| Vehicle adapter body | 1 | black ASA | 15% infill, requires 15 mm outer brim |
| Vehicle adapter cover | 1 | black ASA | 15% infill |
| Latch | 2 | black ASA | 100% infill |

---

## 2) Assemble Vehicle Adapter Board

2.1) Super glue a MISTA 12-pin male connector to the vehicle adapter board (plastic-to-board contact, don't glue the metal contacts!)
<p align="center">
  
</p>

2.2) Solder the connector to the board\
<p align="center">
  
</p>

2.3) Cut a black 8 AWG wire to 70 mm & solder to the antispark board 'batt-' terminal
<p align="center">
  
</p>

2.4) Cut a black 8 AWG wire to 128 mm & solder to the antispark board 'load-' terminal
<p align="center">
  
</p>

2.5) Cut a red 22 AWG wire to 90 mm & solder to the antispark board 'batt+' terminal
<p align="center">
  
</p>

2.6) Solder the black 8 AWG wire coming off the antispark board 'batt-' terminal to the vehicle adapter board 'Vbatt-' terminal
<p align="center">
  
</p>

2.7) Cut a red 8 AWG wire to 200 mm length & solder it to the vehicle adapter board 'Vbatt+' terminal
<p align="center">
  
</p>
2.8) Solder the red 22 AWG wire coming off the antispark board 'batt+' terminal to the vehicle adapter board 'Vbatt+' terminal
<p align="center">
  
</p>

2.9) Place a large, clear heat shrink tube over the antispark board & shrink it down
<p align="center">
  
</p>

2.10) Place dabs of glue at the glue points on the vehicle adapter board, then glue the cover to it
<p align="center">
  
  
</p>

*This concludes the vehicle adapter board build*

> **NOTICE:** the XT90 connector remains separate from the 8 AWG wires protruding from the vehicle adapter board. The proper wire length will be determined upon bolting the vehicle adapter onto the vehicle, at which time the wires can be trimmed to length & soldered to the XT90 connector.
> <p align="center">
>  
></p>

---

## 3) Assemble the Vehicle Adapter

3.1) Insert the rounded dowel pins into the 3D-printed vehicle adapter body
<p align="center">
  
</p>

3.2) Insert the vehicle adapter board into the vehicle adapter body, & fasten using four M3 × 6 mm bolts
<p align="center">
  
</p>

*This concludes the vehicle adapter build*

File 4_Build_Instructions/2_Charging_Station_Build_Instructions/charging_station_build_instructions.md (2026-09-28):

# Charging Station Build Instructions

## Outline
1. 3D print the parts
2. Assemble the charging station board
3. Assemble the charging station

---

## 1) 3D Print the Parts

| Part | Quantity | Filament | Print Settings |
| :--- | :--- | :--- | :--- |
| Charging station body | 1 | black ASA | 15% infill, requires 15mm outer brim |
| Charging station cover | 1 | black ASA | 15% infill |

---

## 2) Assemble the Charging Station Board

2.1) Place dab of super glue on bottom surface of MISTA 12 pin male connector & place on the charging station PCB, on the side w/ glue point labels
<p align="center">
  
</p>

2.2) Place dab of super glue on bottom surfaces of two JST-XH 4-pin male connector & place on PCB. Ensure that the notches in the JST-XH connectors face toward the MISTA connector
<p align="center">
  
</p>

2.3) Solder pins of MISTA & JST connectors to PCB
<p align="center">
  
</p>

2.4) Solder the wires on the JST-XH male connector to the "balance wire" solder pads, starting with the red wire to "Vbatt" & proceeding in order to the final wire on "GND".
<p align="center">
  
</p>

2.5) Cut black 12 AWG wire to 56 mm length & solder to 'batt-' terminal of antispark PCBA.
<p align="center">
  
</p>

2.6) Cut black 12 AWG wire to 135 mm length & solder to 'load-' terminal of antispark PCBA.
<p align="center">
  
</p>

2.7) Cut red 22 AWG wire to 80 mm length & solder to 'batt+' terminal of antispark PCBA.
<p align="center">
  
</p>

2.8) Solder the short black 12 AWG wire from antispark PCBA to GND terminal on charging station board.
<p align="center">
  
</p>

2.9) Cut red 12 AWG wire to 200 mm & solder to Vbatt terminal on charging station board.
<p align="center">
  
</p>

2.10) Solder the other end of the red 22 AWG wire coming off the antispark PCBA to the charging station board's Vbatt terminal.
<p align="center">
  
</p>

2.11) Pulling the red & black 12 AWG wire such that they are taut & parallel, then place heat shrink tube over the antispark circuit & shrink it down w/ heat gun.
<p align="center">
  
</p>

2.12) Place heat shrink tube having 50mm length over the red & black 12AWG wires & shrink down.
<p align="center">
  
</p>

2.13) If one of the 12 AWG wires is longer, then trim it to make them equal length. Then, solder XT60 connector, with red to + terminal & black to - terminal.
<p align="center">
  
</p>

2.14) On the charging station board, place dabs of glue at the glue points and press the 3D printed cover to the surface. Let dry for ~30s.
<p align="center">
  
  
</p>

*This concludes charging station board assembly*

---

## 3) Assemble the Charging Station

3.1) Insert the rounded dowel pins into the 3D printed charging station body.
<p align="center">
  
</p>

3.2) Insert fully assembled charging station board into charging station body. Fasten using four M3x6mm bolts.
<p align="center">
  
</p>

*This concludes the charging station assembly*

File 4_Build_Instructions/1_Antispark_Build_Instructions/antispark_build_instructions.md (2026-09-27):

## Antispark Printed Circuit Board Assembly (PCBA) Build Instructions

1. Apply solder paste to all the pads on the PCB
2. Populate the PCB with SMD components from the antispark BOM, minus the SMD MOSFETs
3. Solder the SMD components to the board via hot plate
4. Let the board cool down, then flip it over & hand-solder the MOSFETs to their pads
5. Finally, hand-solder the through-hole resistor to its pads & snip its excess legs

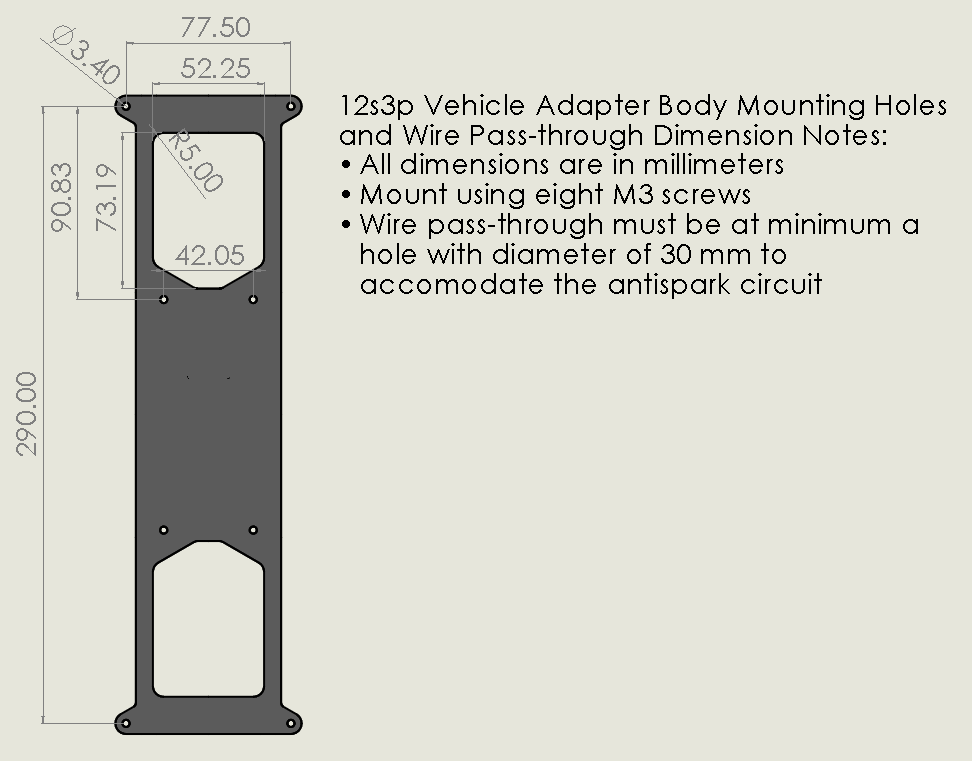
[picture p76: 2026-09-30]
5_Integration_and_Test_Instructions/1_Vehicle_Adapter_Integration_Instructions/Images/12s3p_vehicle_adapter_dimensions.png

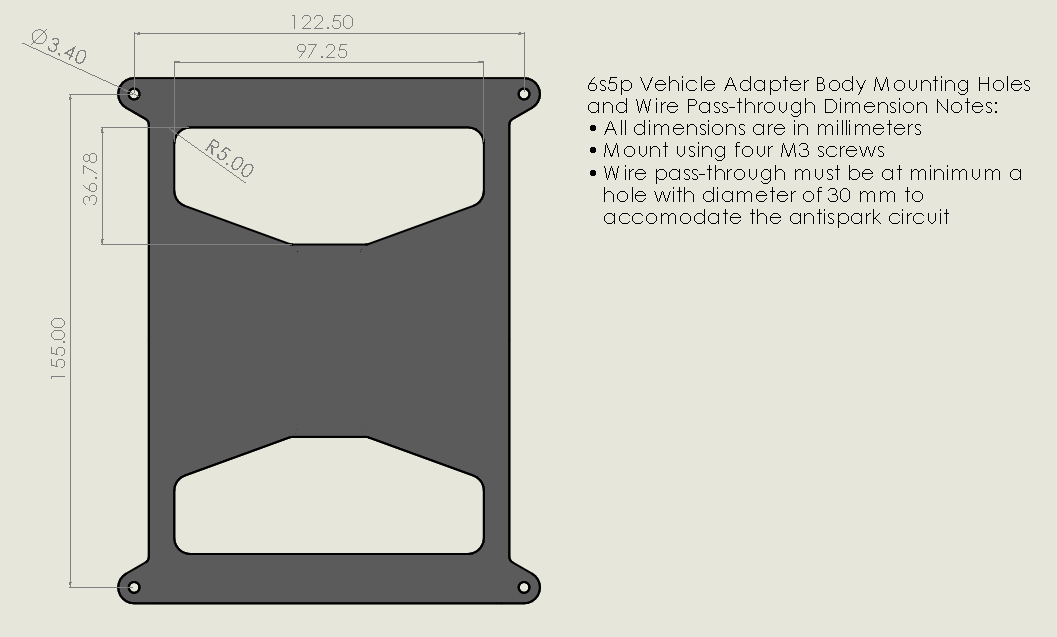
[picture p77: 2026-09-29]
5_Integration_and_Test_Instructions/1_Vehicle_Adapter_Integration_Instructions/Images/6s5p_vehicle_adapter_dimensions.png

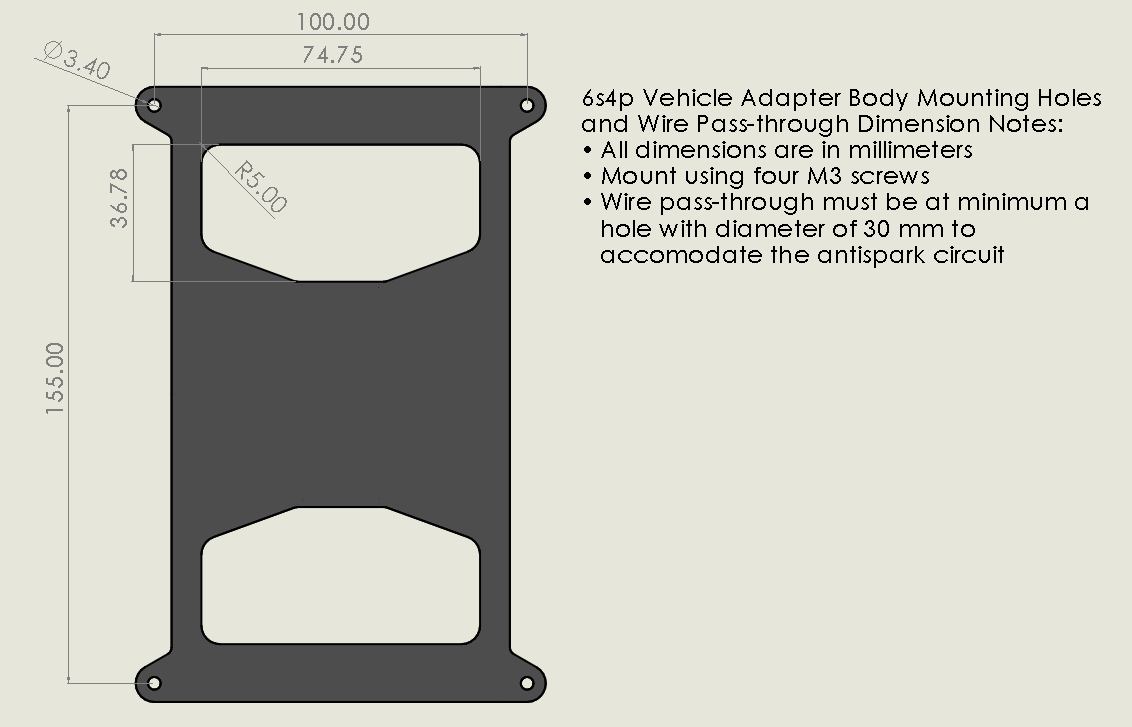
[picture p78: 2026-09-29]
5_Integration_and_Test_Instructions/1_Vehicle_Adapter_Integration_Instructions/Images/6s4p_vehicle_adapter_dimensions.png

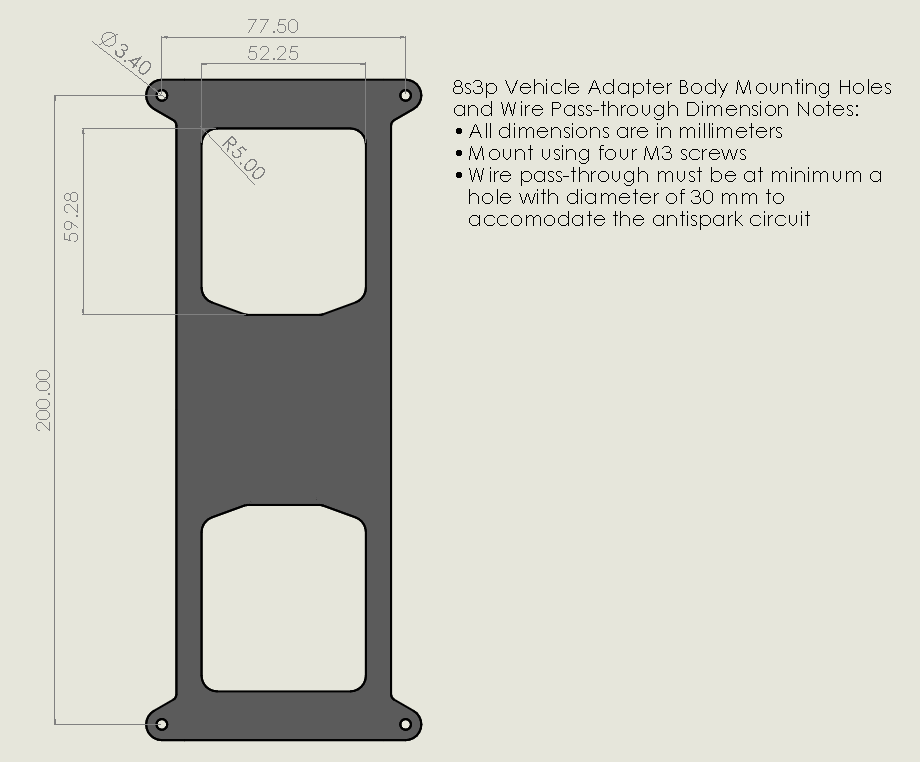
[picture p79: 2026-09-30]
5_Integration_and_Test_Instructions/1_Vehicle_Adapter_Integration_Instructions/Images/8s3p_vehicle_adapter_dimensions.png

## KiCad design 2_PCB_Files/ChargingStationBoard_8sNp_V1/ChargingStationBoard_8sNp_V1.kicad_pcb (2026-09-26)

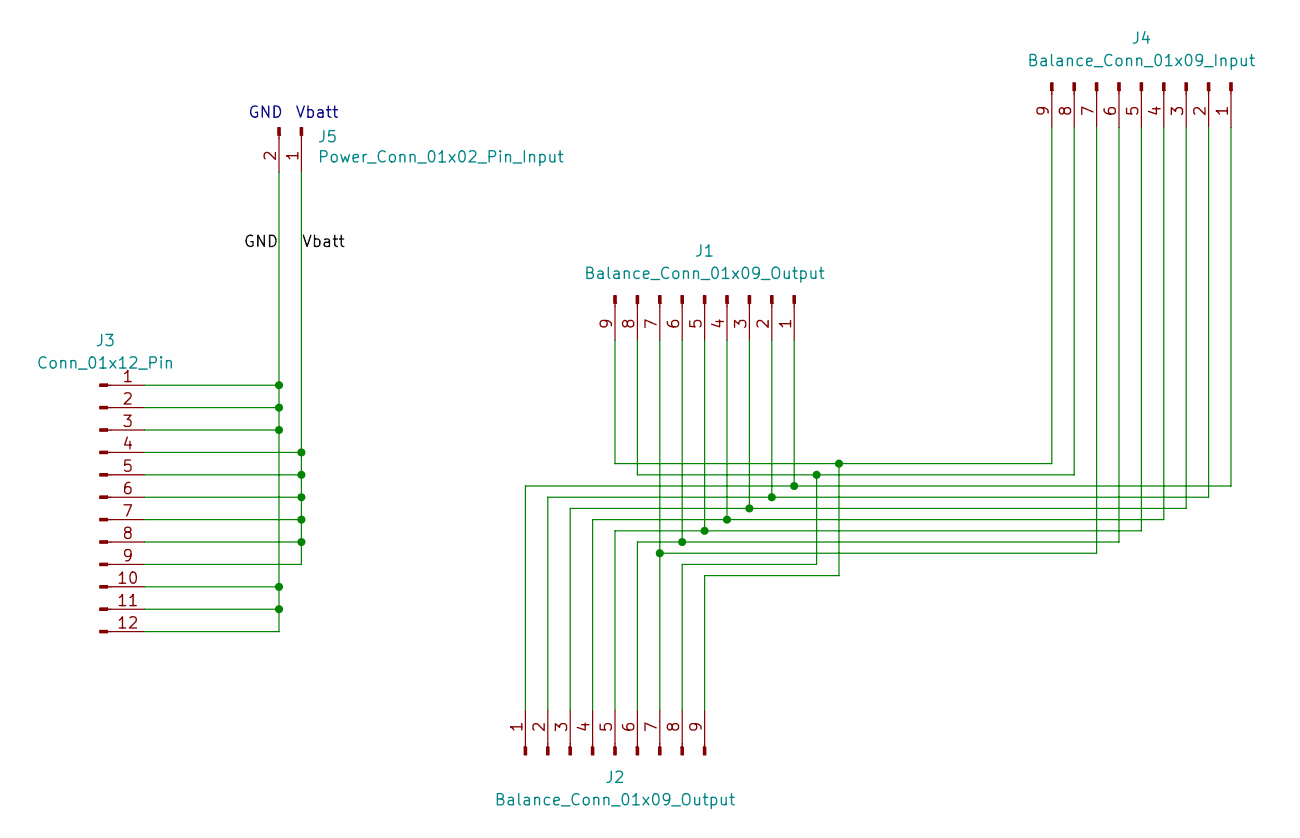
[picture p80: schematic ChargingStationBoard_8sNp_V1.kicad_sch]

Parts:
J1, J2: Balance_Conn_01x09_Output; JST_XH_B9B-XH-A_1x09_P2.50mm_Vertical
J3: Conn_01x12_Pin; MISTA_MSD-DB01M
J4: Balance_Conn_01x09_Input; misc_pads_9_pin_1.75mmx1.75mm
J5: Power_Conn_01x02_Pin_Input; power_pads_2_pins_8mmx8mm

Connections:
/GND: J3.1, J3.2, J3.3, J3.10, J3.11, J3.12, J5.2
/Vbatt: J3.4, J3.5, J3.6, J3.7, J3.8, J3.9, J5.1
unnamed: J1.1, J2.1, J4.1
unnamed: J1.2, J2.2, J4.2
unnamed: J1.3, J2.3, J4.3
unnamed: J1.4, J2.4, J4.4
unnamed: J1.5, J2.5, J4.5
unnamed: J1.6, J2.6, J4.6
unnamed: J1.7, J2.7, J4.7
unnamed: J1.8, J2.8, J4.8
unnamed: J1.9, J2.9, J4.9

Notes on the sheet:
GND
Vbatt

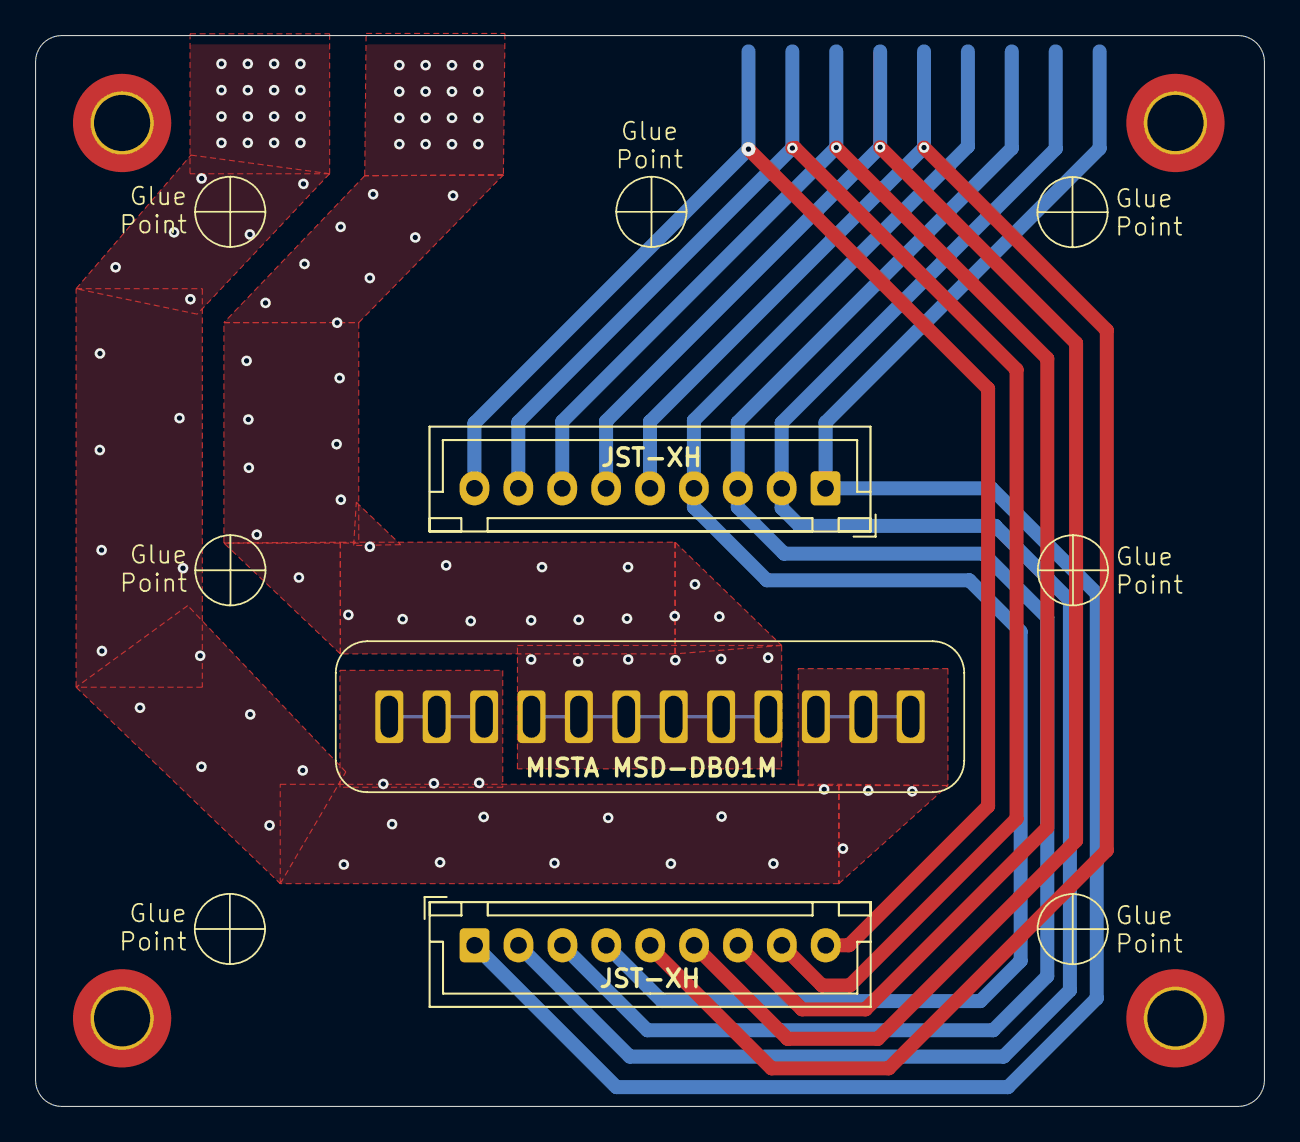
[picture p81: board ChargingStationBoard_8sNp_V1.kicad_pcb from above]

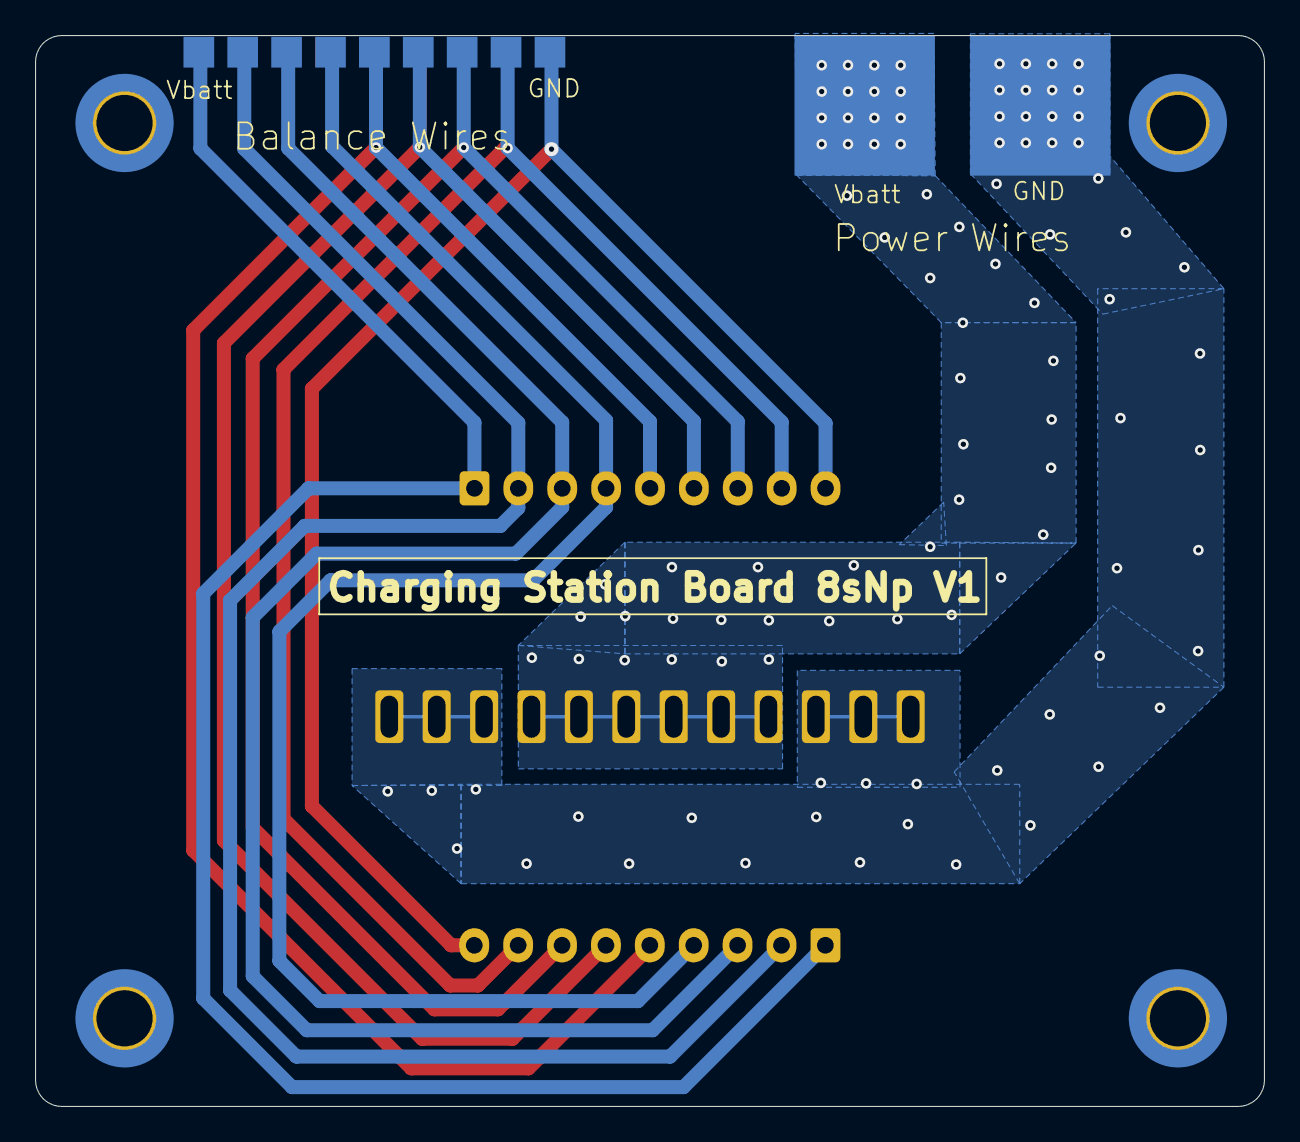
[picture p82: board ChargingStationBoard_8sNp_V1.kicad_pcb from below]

Board: 4 copper layers, 70.0 x 61.0 mm, 5 parts (2 on the bottom side), 11 nets.

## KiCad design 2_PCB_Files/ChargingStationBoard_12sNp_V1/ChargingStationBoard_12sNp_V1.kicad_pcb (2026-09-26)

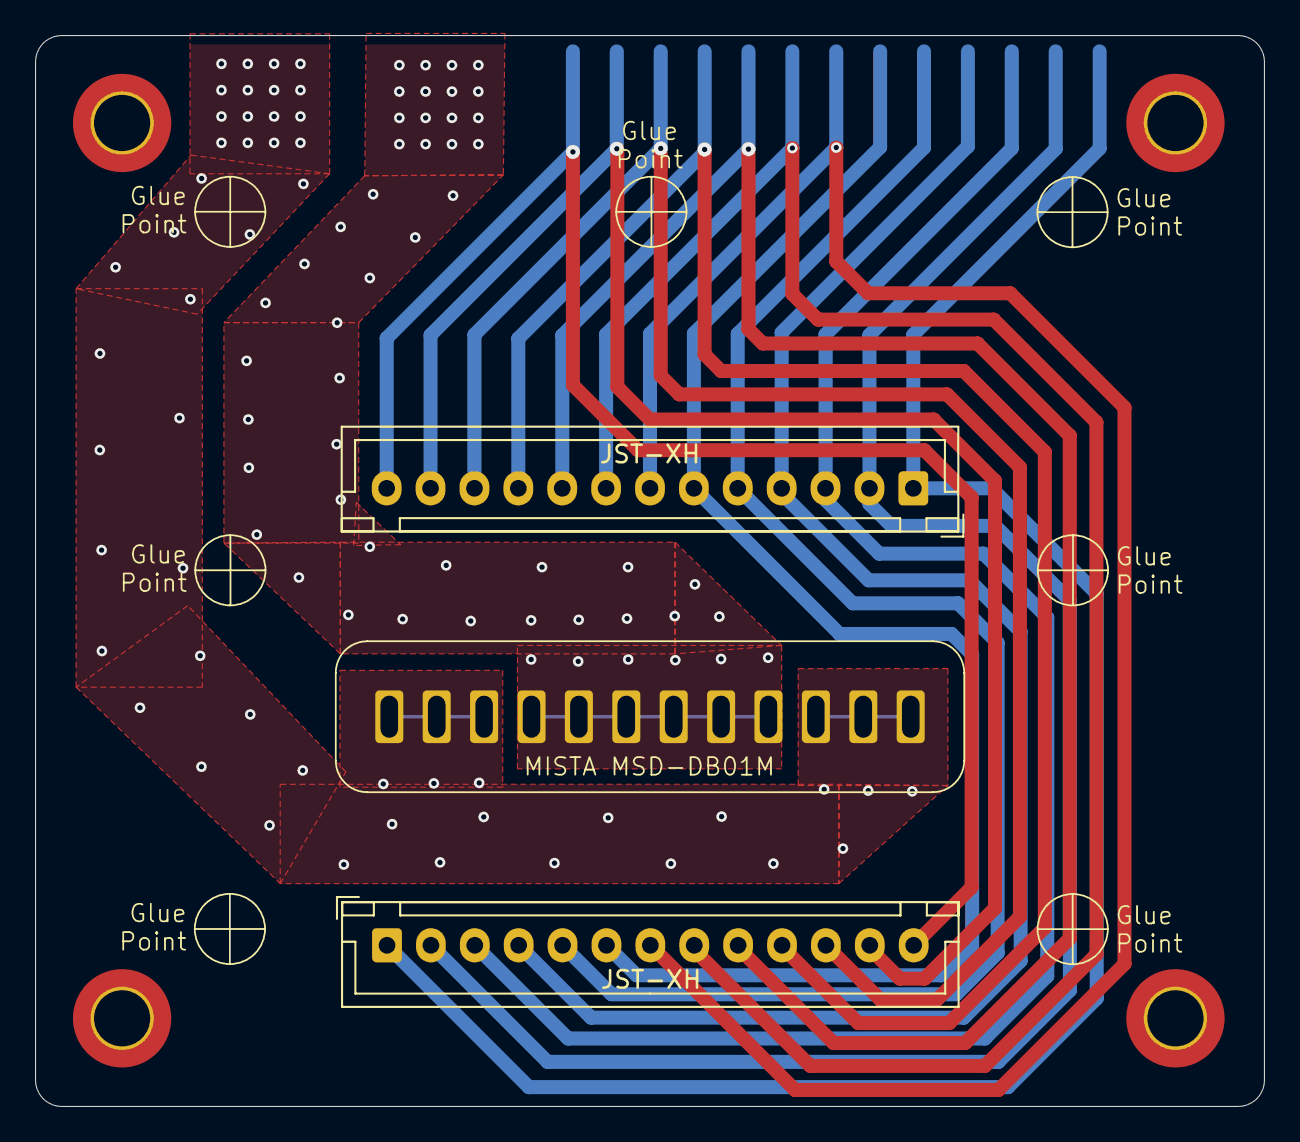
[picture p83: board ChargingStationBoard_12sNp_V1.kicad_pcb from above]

Board: 4 copper layers, 70.0 x 61.0 mm, 5 parts (1 on the bottom side), 15 nets.

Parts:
J4: Balance_Conn_01x13_Pin_Input; balance_pads_13_pin
J5: Power_Conn_01x02_Pin_Input; power_pads_2_pins
JST-XH: Balance_Conn_01x13_Output; JST_XH_B13B-XH-A_1x13_P2.50mm_Vertical
JST-XH#2: Balance_Conn_01x13_Pin_Output; JST_XH_B13B-XH-A_1x13_P2.50mm_Vertical
MISTA MSD-DB01M: Conn_01x12_Pin; MISTA_MSD-DB01

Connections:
/GND: J5.2, MISTA MSD-DB01M.1, MISTA MSD-DB01M.2, MISTA MSD-DB01M.3, MISTA MSD-DB01M.10, MISTA MSD-DB01M.11, MISTA MSD-DB01M.12
/Vbatt: J5.1, MISTA MSD-DB01M.4, MISTA MSD-DB01M.5, MISTA MSD-DB01M.6, MISTA MSD-DB01M.7, MISTA MSD-DB01M.8, MISTA MSD-DB01M.9
unnamed: J4.1, JST-XH.1, JST-XH#2.1
unnamed: J4.2, JST-XH.2, JST-XH#2.2
unnamed: J4.3, JST-XH.3, JST-XH#2.3
unnamed: J4.4, JST-XH.4, JST-XH#2.4
unnamed: J4.5, JST-XH.5, JST-XH#2.5
unnamed: J4.6, JST-XH.6, JST-XH#2.6
unnamed: J4.7, JST-XH.7, JST-XH#2.7
unnamed: J4.8, JST-XH.8, JST-XH#2.8
unnamed: J4.9, JST-XH.9, JST-XH#2.9
unnamed: J4.10, JST-XH.10, JST-XH#2.10
unnamed: J4.11, JST-XH.11, JST-XH#2.11
unnamed: J4.12, JST-XH.12, JST-XH#2.12
unnamed: J4.13, JST-XH.13, JST-XH#2.13

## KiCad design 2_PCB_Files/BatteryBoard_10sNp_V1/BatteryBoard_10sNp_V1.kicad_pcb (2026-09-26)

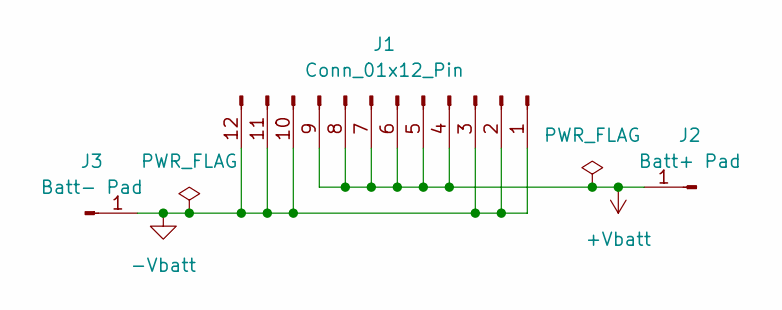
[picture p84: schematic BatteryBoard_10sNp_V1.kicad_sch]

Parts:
J1: Conn_01x12_Pin; MISTA_MSD-DB01F
J2: Batt+ Pad; pad_10p5mmx6mm
J3: Batt- Pad; pad_10p5mmx6mm

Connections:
+Vbatt: J1.4, J1.5, J1.6, J1.7, J1.8, J1.9, J2.1
-Vbatt: J1.1, J1.2, J1.3, J1.10, J1.11, J1.12, J3.1

Board: 6 copper layers, 3 parts (3 on the bottom side), 2 nets, no tracks yet.

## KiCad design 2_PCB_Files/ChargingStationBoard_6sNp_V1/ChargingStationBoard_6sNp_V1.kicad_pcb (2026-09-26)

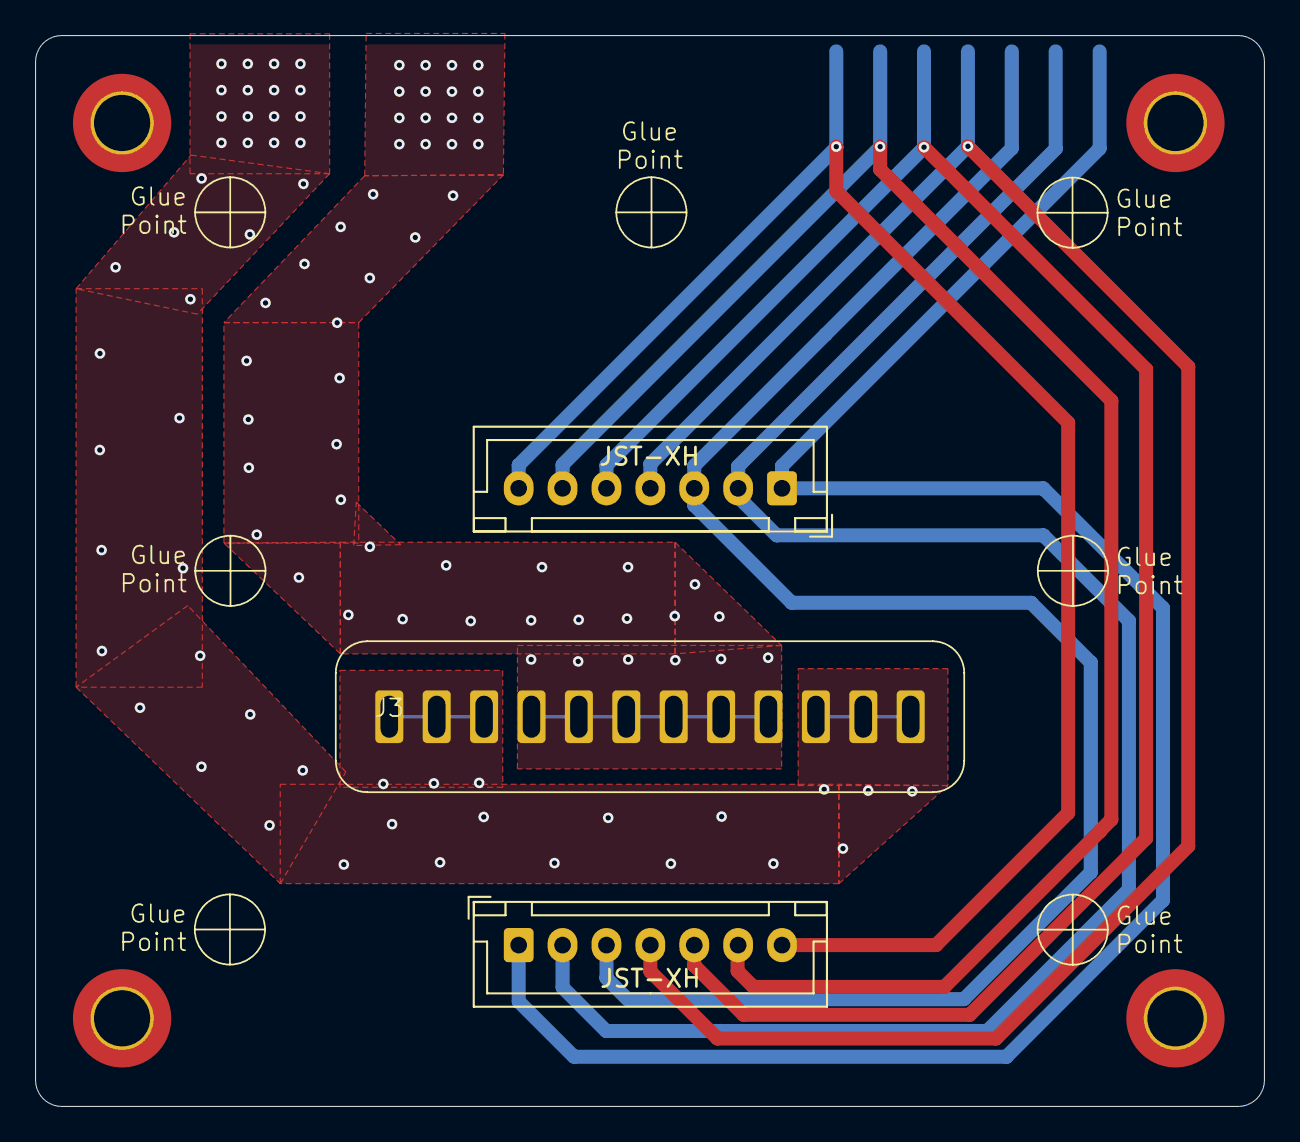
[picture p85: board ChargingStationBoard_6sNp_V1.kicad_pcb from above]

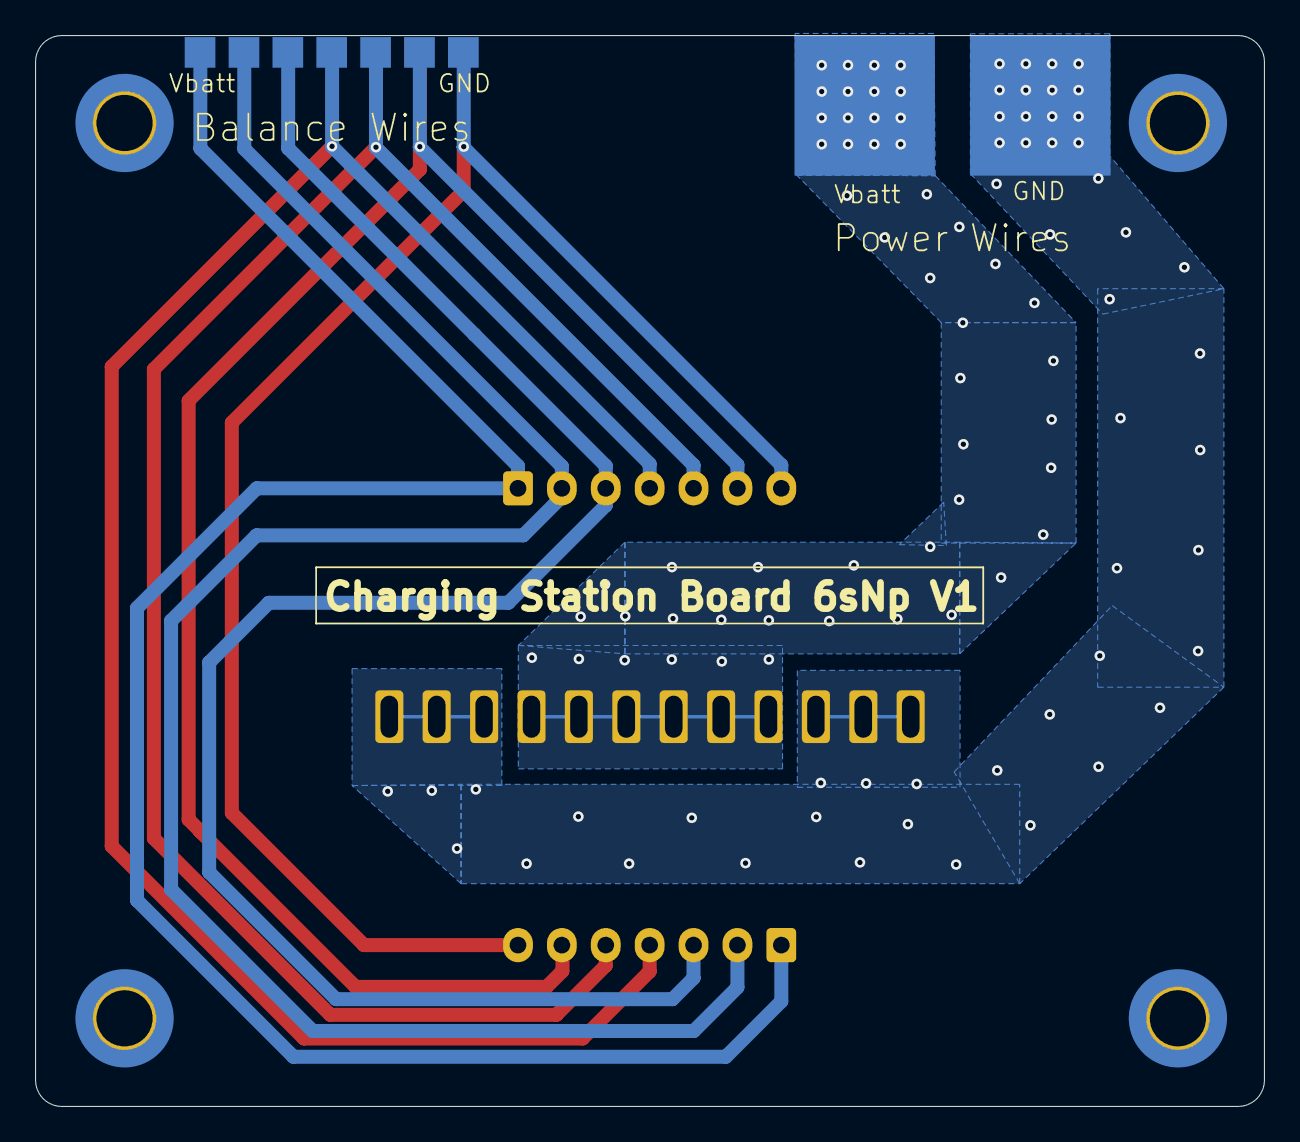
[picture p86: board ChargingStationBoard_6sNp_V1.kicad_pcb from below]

Board: 4 copper layers, 70.0 x 61.0 mm, 5 parts (2 on the bottom side), 9 nets.

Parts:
J1: Conn_01x07_Pin_Input; misc_pads_7_pin_1.75mmx1.75mm
J3: Conn_01x12_Pin; MISTA_MSD-DB01M
J5: Power_Conn_01x02_Pin_Input; power_pads_2_pins_8mmx8mm
JST-XH: Conn_01x07_Pin_Output; JST_XH_B7B-XH-A_1x07_P2.50mm_Vertical
JST-XH#2: Conn_01x07_Pin_Output; JST_XH_B7B-XH-A_1x07_P2.50mm_Vertical

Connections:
/GND: J3.1, J3.2, J3.3, J3.10, J3.11, J3.12, J5.2
/Vbatt: J3.4, J3.5, J3.6, J3.7, J3.8, J3.9, J5.1
unnamed: J1.1, JST-XH.1, JST-XH#2.1
unnamed: J1.2, JST-XH.2, JST-XH#2.2
unnamed: J1.3, JST-XH.3, JST-XH#2.3
unnamed: J1.4, JST-XH.4, JST-XH#2.4
unnamed: J1.5, JST-XH.5, JST-XH#2.5
unnamed: J1.6, JST-XH.6, JST-XH#2.6
unnamed: J1.7, JST-XH.7, JST-XH#2.7

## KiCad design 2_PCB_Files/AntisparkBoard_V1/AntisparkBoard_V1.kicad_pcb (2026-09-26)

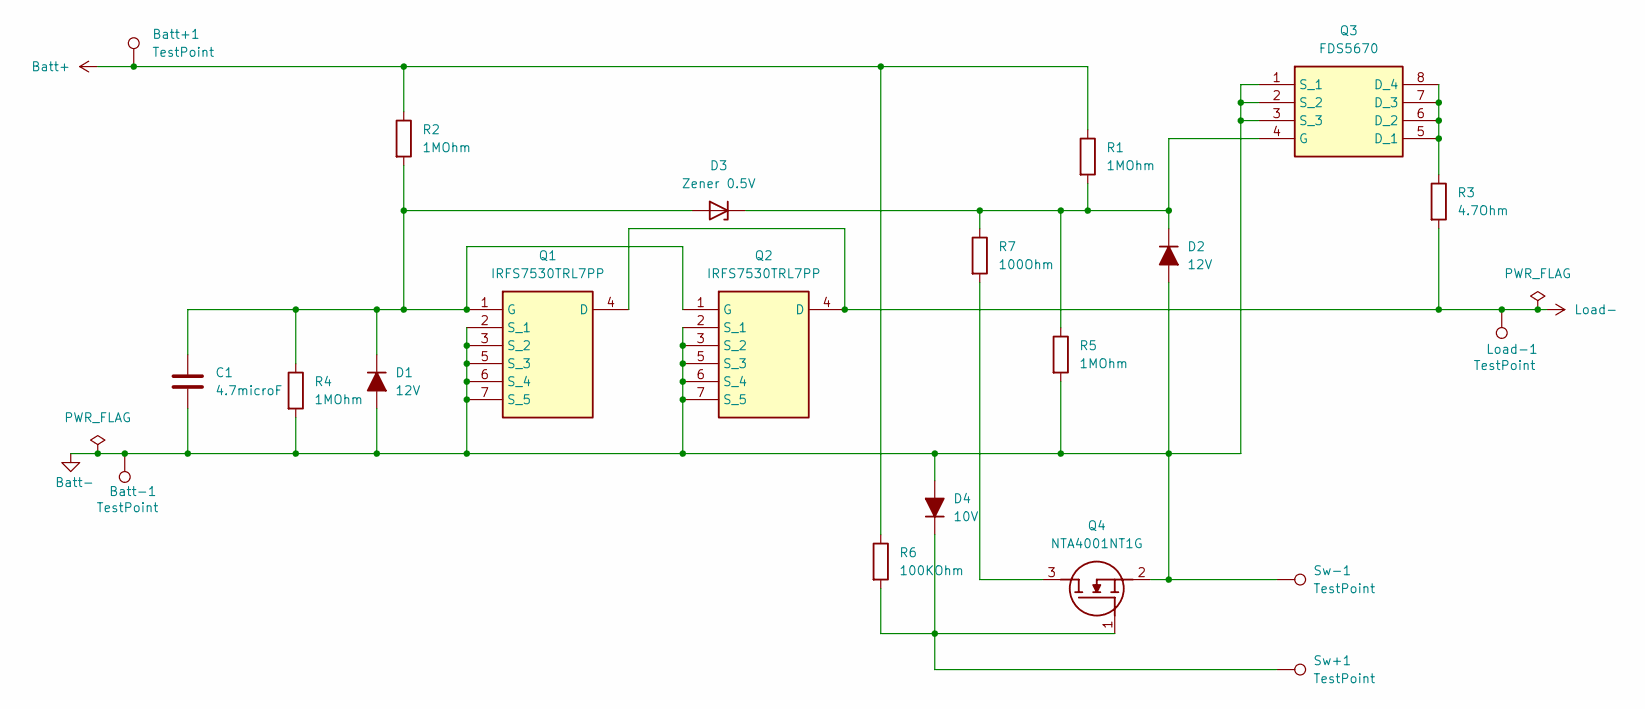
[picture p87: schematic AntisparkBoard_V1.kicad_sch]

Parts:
Batt+1: TestPoint; TestPoint_Pad_D2.0mm
Batt-1: TestPoint; pad_6mmx6mm
C1: 4.7microF; C_0805_2012Metric
D1, D2: 12V; D_MiniMELF
D3: Zener 0.5V; D_SOD-123
D4: 10V; D_SOD-323
Load-1: TestPoint; pad_6mmx6mm
Q1, Q2: IRFS7530TRL7PP; Manufacturer_Part_Number IRFS7530TRL7PP; Mouser Part Number 942-IRFS7530TRL7PP
Q3: FDS5670; SOIC127P600X175-8N; Manufacturer_Part_Number FDS5670; Mouser Part Number 512-FDS5670
Q4: NTA4001NT1G; SOT50P160X90-3N; Manufacturer_Part_Number NTA4001NT1G; Mouser Part Number 863-NTA4001NT1G
R1, R2, R4, R5: 1MOhm; R_0603_1608Metric
R3: 4.7Ohm; R_Axial_DIN0414_L11.9mm_D4.5mm_P15.24mm_Horizontal
R6: 100KOhm; R_0603_1608Metric
R7: 100Ohm; R_0603_1608Metric
Sw+1: TestPoint; TestPoint_Pad_D2.0mm
Sw-1: TestPoint; TestPoint_Pad_D2.0mm

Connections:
Batt+: Batt+1.1, R1.1, R2.1, R6.1
Batt-: Batt-1.1, C1.2, D1.2 (A), D2.2 (A), D4.2 (A), Q1.2 (S_1), Q1.3 (S_2), Q1.5 (S_3), Q1.6 (S_4), Q1.7 (S_5), Q2.2 (S_1), Q2.3 (S_2), Q2.5 (S_3), Q2.6 (S_4), Q2.7 (S_5), Q3.1 (S_1), Q3.2 (S_2), Q3.3 (S_3), Q4.2 (S), R4.2, R5.2, Sw-1.1
Load-: Load-1.1, Q1.4 (D), Q2.4 (D), R3.2
unnamed: C1.1, D1.1 (K), D3.2 (A), Q1.1 (G), Q2.1 (G), R2.2, R4.1
unnamed: D2.1 (K), D3.1 (K), Q3.4 (G), R1.2, R5.1, R7.1
unnamed: D4.1 (K), Q4.1 (G), R6.2, Sw+1.1
unnamed: Q3.5 (D_1), Q3.6 (D_2), Q3.7 (D_3), Q3.8 (D_4), R3.1
unnamed: Q4.3 (D), R7.2

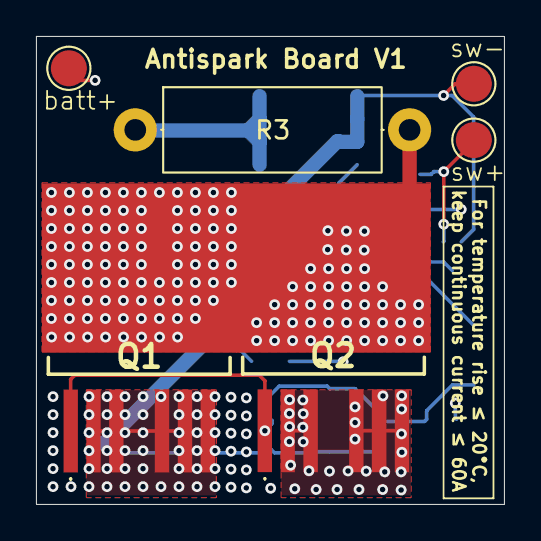
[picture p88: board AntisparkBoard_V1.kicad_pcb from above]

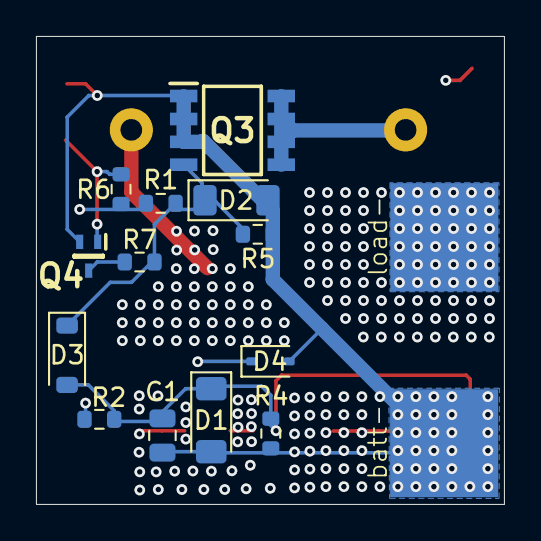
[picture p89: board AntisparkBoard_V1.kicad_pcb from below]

Board: 8 copper layers, 26.0 x 26.0 mm, 21 parts (15 on the bottom side), 8 nets.

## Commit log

2026-09-25 Create Charging_Station_Build_Images
2026-09-27 Create battery_bom.md
